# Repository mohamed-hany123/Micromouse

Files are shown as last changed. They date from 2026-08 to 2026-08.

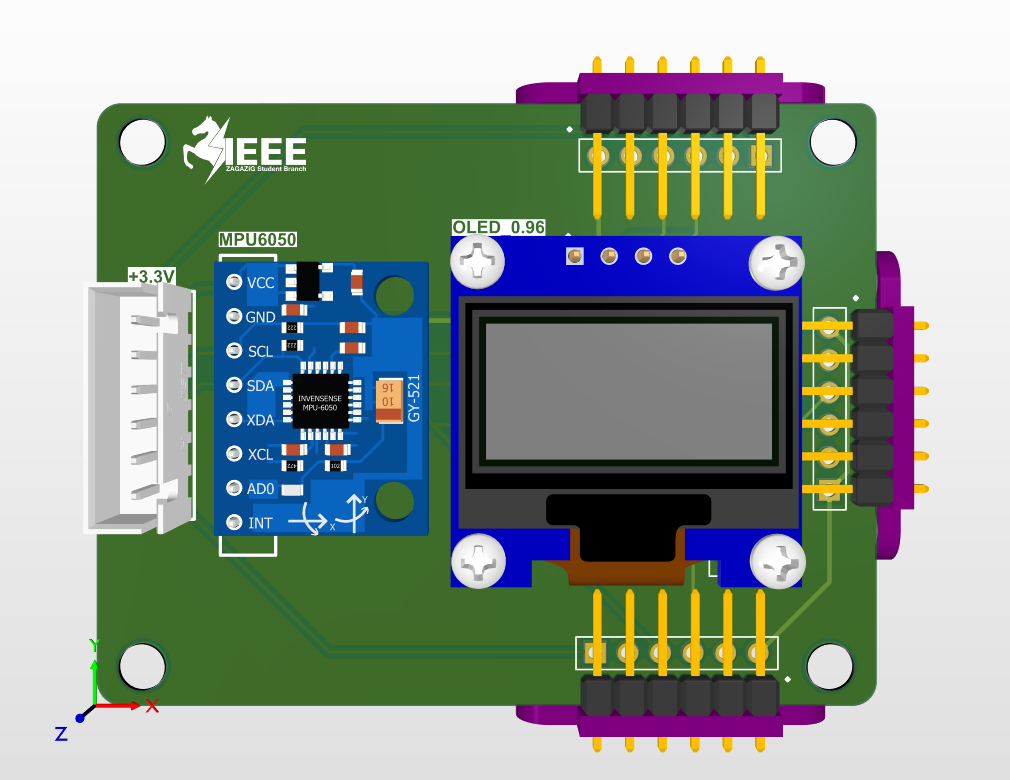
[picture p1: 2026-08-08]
media/Top_Floor_3d.png

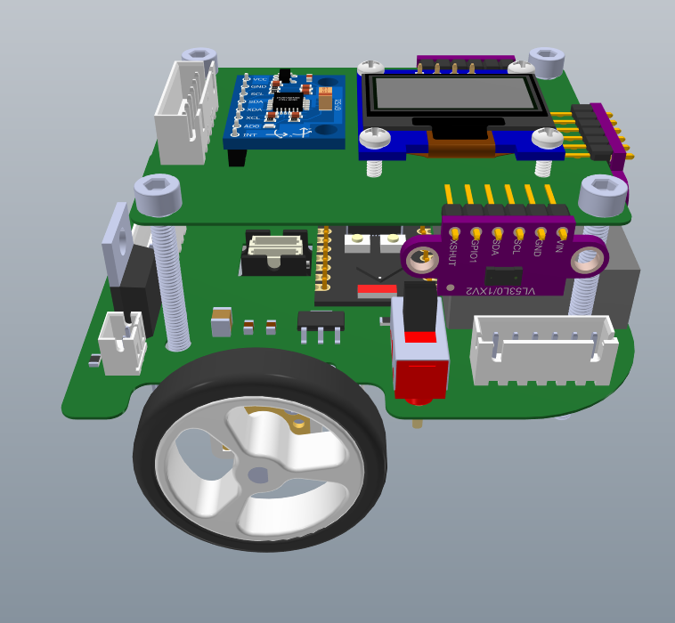
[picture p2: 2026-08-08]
media/3D_View.png

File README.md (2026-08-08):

# Micromouse
Micromouse robot designed for the IEEE Zagazig competition
# 🐭 Micromouse Robot

A custom-designed autonomous **Micromouse robot** developed for the **IEEE Zagazig competition**, where our team achieved **2nd place**.

The robot is designed to autonomously navigate a maze using distance sensors, determine its position and orientation, and control two DC motors for accurate movement.

> 🥈 **Competition Result: 2nd Place — IEEE Zagazig**

---

## 🏆 Competition

This project was developed and tested for an **IEEE Zagazig Micromouse competition**.

Our team achieved:

**🥈 2nd Place**

The competition required the robot to autonomously navigate a maze while accurately controlling its movement and responding to the maze structure.

---

## 🚀 Project Overview

The Micromouse is a small autonomous robot capable of navigating a maze without external control.

The robot uses multiple distance sensors to detect walls and obstacles, an IMU to measure orientation, wheel encoders for movement feedback, and a microcontroller to process sensor data and control the motors.

The project includes both the **electronic hardware** and **custom PCB design** developed specifically for the robot.

### Main Features

* Autonomous maze navigation
* Three front/side-facing ToF distance sensors
* Wheel encoder feedback
* IMU-based orientation measurement
* Closed-loop motor control
* Custom PCB designed in Altium Designer
* Dual DC motor drive
* Compact two-layer PCB design
* Dedicated power distribution and decoupling
* I²C communication between the ESP32-C3 and sensors

---

# 🧠 System Architecture

The main system can be divided into four sections:

```text
                  ┌──────────────────┐
                  │    ESP32-C3      │
                  │   Main MCU       │
                  └────────┬─────────┘
                           │
          ┌────────────────┼────────────────┐
          │                │                │
          ▼                ▼                ▼
   ┌────────────┐   ┌────────────┐   ┌────────────┐
   │ VL53L0X ×3 │   │  MPU6050   │   │  Encoders  │
   │ ToF Sensors│   │    IMU     │   │            │
   └────────────┘   └────────────┘   └────────────┘
                           │
                           │
                           ▼
                    ┌────────────┐
                    │  Control   │
                    │ Algorithms │
                    └─────┬──────┘
                          │
                          ▼
                    ┌────────────┐
                    │  DRV8833   │
                    │ Motor Driver│
                    └─────┬──────┘
                          │
                    ┌─────┴─────┐
                    ▼           ▼
                 Motor L     Motor R
```

---

# 🔌 Hardware

## Main Controller

### ESP32-C3

The **ESP32-C3** acts as the main controller of the robot.

It is responsible for:

* Reading the distance sensors
* Reading IMU data
* Processing encoder feedback
* Running the navigation and control algorithms
* Generating motor control signals
* Communicating with the peripheral devices through I²C and GPIO

---

## 📡 Distance Sensors

The robot uses **three VL53L0X Time-of-Flight sensors** for wall detection.

The sensors provide distance measurements that are used to determine the robot's position relative to the maze walls.

Using three sensors allows the robot to obtain information from multiple directions while navigating.

### I²C Addressing

Because the VL53L0X sensors share the same default I²C address, the design uses the sensors' shutdown/control pins to initialize them individually and assign unique I²C addresses.

This allows all three sensors to operate on the same I²C bus.

---

## 🧭 MPU6050

An **MPU6050 IMU** is used to obtain orientation and motion information.

The IMU provides:

* 3-axis accelerometer
* 3-axis gyroscope

The gyroscope data can be used to estimate the robot's rotation during turns and improve movement accuracy.

---

## ⚙️ Motor Driver

The robot uses a **DRV8833 dual H-bridge motor driver** to control the two DC motors.

The driver provides independent control of:

* Left motor
* Right motor

The ESP32-C3 generates the required control signals to control motor direction and speed.

---

## 🔄 Encoders

The motors include wheel encoders that provide feedback about wheel rotation.

Encoder feedback allows the controller to estimate:

* Distance traveled
* Wheel speed
* Difference between left and right wheel movement
* Movement accuracy during straight-line motion
* Rotation during turns

This feedback is important for implementing closed-loop motion control.

---

# 🖥️ PCB Design

The PCB was designed using **Altium Designer**.

The custom board integrates the major electronics required by the Micromouse into a single compact PCB.

### PCB Design Considerations

Several design considerations were taken into account during PCB development:

* Power distribution
* Decoupling capacitors
* Motor-driver current paths
* Sensor communication
* I²C routing
* Grounding
* Separation of noisy motor circuitry from sensitive sensors
* Compact component placement
* Connector accessibility
* Manufacturability

The PCB contains dedicated circuitry for the MCU, sensors, motor driver, power system, and external connections.

---

# ⚡ Power System

The PCB includes the required power distribution for the robot's electronics and motors.

Separate consideration was given to the motor supply and the low-voltage digital electronics to reduce the effect of motor switching noise on the sensors and microcontroller.

Decoupling capacitors were placed close to the relevant IC power pins to improve supply stability and reduce high-frequency noise.

---

# 📐 Hardware Files

The repository contains the hardware design files used during development.

The hardware files include the PCB design, schematic, component libraries, manufacturing files, and other supporting design files.

---

# 🧪 Testing & Verification

The hardware was tested throughout the development process before being used in the competition.

Testing included:

* Power supply verification
* Motor driver testing
* Sensor communication testing
* I²C communication
* Encoder feedback
* IMU measurements
* Motor direction and speed control
* PCB electrical-rule checking
* PCB design-rule checking
* Full robot movement testing
* Maze navigation testing

---

# 🛠️ Tools & Technologies

| Category | Technology |
| --- | --- |
| Microcontroller  | ESP32-C3 |
| Distance Sensors | VL53L0X ×3 |
| IMU | MPU6050 |
| Motor Driver | DRV8833 |
| Motors | DC Gear Motors with Encoders |
| PCB Design | Altium Designer |
| Communication | I²C |
| Motor Control | PWM |
| Programming | C / Embedded C |
| Manufacturing | Custom PCB |

---

# 📁 Repository Structure

```
Micromouse/
│
├── Hardware/
│    ├── Bottom_Floor/
│    ├── Full_project/
│    ├── Top_floor/
│   
│  
│
│
├── docs/
│      Micromouse_BOM.pdf
│      Micromouse_Calculations_IEEE_RAS.pdf
│
├── Media/
│   ├── Images
│
│
└── README.md
```

---

# 👥 Team

This was a team project developed for the IEEE Zagazig competition.

**Team Members:**

* Mohamed Hany 
* Abdallah Ahmed

### My Contribution

My main contributions to the project included:

* PCB design and development
* Schematic design
* Component selection
* ESP32-C3 hardware integration
* Sensor integration
* Motor-driver integration
* Power distribution
* PCB routing and layout
* Hardware testing and debugging

# 🏁 Result

## 🥈 2nd Place — IEEE Zagazig

The completed Micromouse successfully competed in the IEEE Zagazig competition and achieved **2nd place**.

The project provided practical experience in:

* Embedded systems
* PCB design
* Sensor integration
* Motor control
* Power electronics
* Hardware debugging
* Autonomous robotics
* Team-based engineering

---

# 📜 License

This project is provided for educational and portfolio purposes.

Please contact the project contributors before using the hardware design commercially.

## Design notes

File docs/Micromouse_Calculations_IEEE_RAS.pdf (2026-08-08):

# Micromouse

## Final Project — Calculations & Justification

IEEE ZSB · RAS Chapter — PCB Design Track Final Project

## 1 PCB Copper Trace Width Calculations

## 2 Power Calculations of All Components

## 3 Microcontroller Selection Justification

## 4 Battery Lifetime Calculations

## 1 PCB Copper Trace Width Calculations

Calculated using the IPC-2221 standard for external (top/bottom layer) traces, 1oz/ft² copper, 10°C allowable temperature rise.

## Area (mils²) = (I / (k × ∆T

0.44))⁽¹/0.725)

## | Width (mils) = Area / 1.37

I = current (A), ∆T = 10°C, k = 0.048.

## 1.1 — Top Floor (Sensors)

Net | Worst-Case I | Calc. Min. | Implemented | Margin
3.3V / GND (power) | 0.139 A | 0.020 mm | 0.3533 mm | 17.7×
Signal traces (SDA, SCL, XSHUT) | < 10 mA | < 0.01 mm | 0.25 mm | Ample

## 1.2 — Bottom Floor (Power, MCU, Motor Driver)

Net | Worst-Case I | Calc. Min. | Implemented | Margin
Main power rail (Fuse → Switch → Protection → VCC) | 0.789 A | 0.218 mm | 0.4 mm | 1.83×
DRV8833 VM | 0.600 A | 0.149 mm | 0.4 mm | 2.68×
Motor outputs → Motor Left / Right (each) | 0.300 A | 0.057 mm | 0.25 mm | 4.39×
Regulator path (7.4V_Safe → AMS1117 → 5V → ESP32) | 0.189 A | 0.030 mm | 0.4 mm | 13.3×
Signal traces (motor control, encoders, ADC divider) | < 10 mA | < 0.01 mm | 0.254 mm | Ample

## 2 Power Calculations of All Components

Calculated using P = V × I at each component's actual operating voltage.

Component | V | I (typ.) | P | Source
ESP32-C3 (active, radios off) | 3.3V | 45 mA | 0.149W | Espressif datasheet
3× VL53L0X ToF (30mA ea.) | 3.3V | 90 mA | 0.297W | ST datasheet
MPU6050 IMU | 3.3V | 3.6 mA | 0.012W | InvenSense datasheet
OLED 0.96in (SSD1306) | 3.3V | 20 mA | 0.066W | Manufacturer datasheet
2× Encoders (10mA ea., estimated) | 3.3V | 20 mA | 0.066W | Estimated
DRV8833 quiescent | 3.3V | 5 mA | 0.017W | Typical
AMS1117-5.0 quiescent | 7.4V | 5 mA | 0.037W | Typical
Battery divider bleed (100k+33k) | 7.4V | 0.056 mA | 0.0004W | Calculated
Q1 (IRF9540) loss — idle | — | @ 0.189A | 0.007W | Rds(on)=0.20Ω
Q1 (IRF9540) loss — typical | — | @ 0.439A | 0.039W | Rds(on)=0.20Ω
Q1 (IRF9540) loss — worst-case | — | @ 0.789A | 0.125W | Rds(on)=0.20Ω
2× N20 motors — typical (estimated) | 7.4V | 250 mA | 1.850W | ~40% of stall
2× N20 motors — worst-case stall | 7.4V | 600 mA | 4.440W | Manufacturer datasheet

## System Totals

Every regulation stage (AMS1117, Super Mini onboard regulator) is linear, not switching — current is approximately conserved through each stage rather than reduced, so every downstream component's current is reflected directly in what the battery must supply.

Scenario | Total Current | Total Power | Q1 Loss Share
Logic + sensors only (motors idle) | 189 mA | 1.399 W | 0.5%
Typical driving (motors normal) | 439 mA | 3.249 W | 1.2%
Worst-case (both motors stalled) | 789 mA | 5.839 W | 2.1%

## 3 Microcontroller Selection Justification

## Chosen microcontroller: ESP32-C3 Super Mini

Required: 4 motor-driver control pins, 4 quadrature encoder channels, a 2-pin I2C bus shared by 5 devices, 2 GPIO-controlled ToF address lines, and 1 ADC pin for battery sensing — 13 GPIOs total.

## 3.1 — ESP32-C3 Super Mini vs. a Standard 30/38-pin ESP32 DevKit

Spec | ESP32-C3 Super Mini | Standard 30/38-pin DevKit
Board footprint | 22.5 × 18 mm = 405 mm² | ~55 × 28 mm = 1,540 mm² (~3.8× larger)
CPU | Single-core RISC-V | Dual-core Xtensa LX6 (higher idle draw)
Onboard extras | Small onboard 3.3V LDO only | USB-UART bridge chip + large USB connector + full regulator
Usable GPIOs | 13 (exact match) | 30-38 (17-25 unused in this design)
Mounting | Pluggable, small 2.54mm header | Larger socket footprint or permanent solder-down
- 405mm² footprint is ~3.8× smaller than a standard DevKit's ~1,540mm² — a direct, quantifiable contribution to the 11×11cm limit and smallest-robot bonus
- A DevKit's onboard USB-UART bridge and full-size USB connector exist only for plug-and-program convenience — functionality this design moves off-board by programming the Super Mini externally before mounting, making that circuitry pure dead weight here
- 13 GPIOs is an exact match to this design's requirement; a 30/38-pin DevKit would leave 17-25 pins permanently unused
- Both chip families include WiFi/BLE by default; since this design uses neither, the smaller/cheaper C3 package is strictly better with no functional trade-off

## 3.2 — Handling the Tight Pin Budget Safely

- GPIO9 (BOOT button pin) carries only a motor-driver output signal, never an encoder input — a driver output is always actively set by firmware and cannot glitch the boot sequence the way an unpredictable encoder state could
- GPIO8 (onboard status LED) is assigned to a non-critical encoder channel — the LED flickering with wheel rotation is cosmetic only

## 4 Battery Lifetime Calculations

## Final Battery Specification

Spec | Value
Type / configuration | 2× 3.7V LiPo cells (ECOCELL) in series = 7.4V nominal
Capacity | 1000 mAh
Dimensions (per cell) | 35 × 25 × 10 mm
Weight (per cell / pair) | 22g / 44g total
Max charge current | 500 mA (0.5C) — per cell, charged individually
Max discharge current | 1000 mA (1C) max; 500 mA (0.5C) recommended continuous
Protection | Built-in per-cell: overcharge, over-discharge, short-circuit

## Step 1 — Runtime at Typical Operating Current

## Runtime (h) = Capacity (Ah) / Current (A)

Runtime = 1.0 Ah / 0.439 A ≈ 2.28 hours (~137 minutes).

## Step 2 — Runtime at Worst-Case Current

Runtime = 1.0 Ah / 0.789 A ≈ 1.27 hours (~76 minutes) — both motors permanently stalled; pessimistic-case only.

## Step 3 — Discharge Rate Check

This battery specifies fixed discharge limits: 500mA recommended continuous, 1000mA absolute maximum. Typical current (439mA) stays under the recommended limit; worst-case current (789mA) exceeds it by 58% but remains under the 1000mA absolute maximum — acceptable for this short-duration competition project.

## Step 4 — Practical Safety Margin for Competition Use

## Required capacity = Current × Runtime needed × 1.25

For a 15-minute session: 0.439A × 0.25h = 0.110 Ah, ×1.25 ≈ 137 mAh minimum. The chosen 1000mAh pack provides over 7× this minimum.

## Step 5 — Charging Procedure

Two independently-protected single cells, not one factory 2S pack — charge each cell individually: disconnect the series link, charge each 3.7V cell separately through its own JST-PH connector at or under 500mA, then reconnect in series for use.

Prepared for IEEE ZSB · RAS chapter - PCB Design track | Final Project: Micromouse

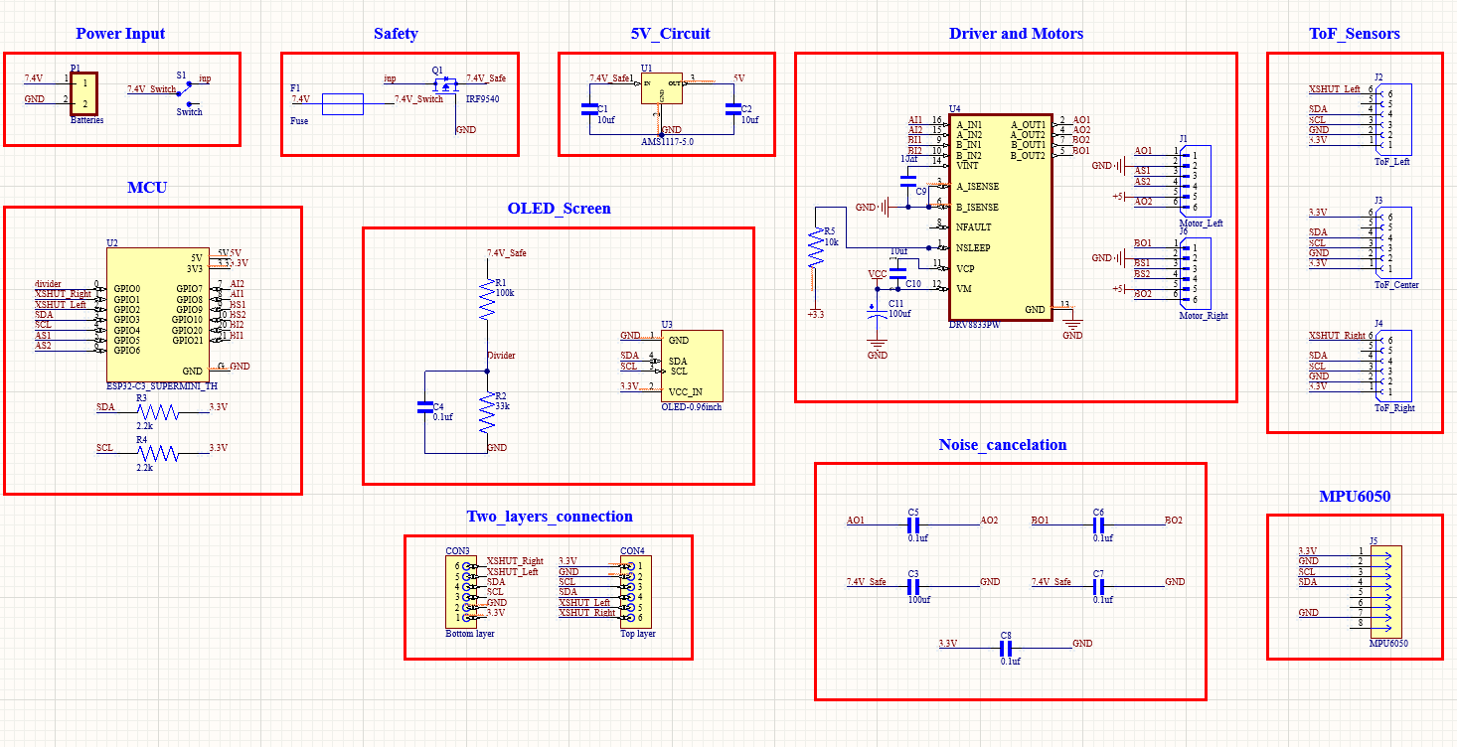
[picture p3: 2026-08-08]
media/Full_Schematic.png

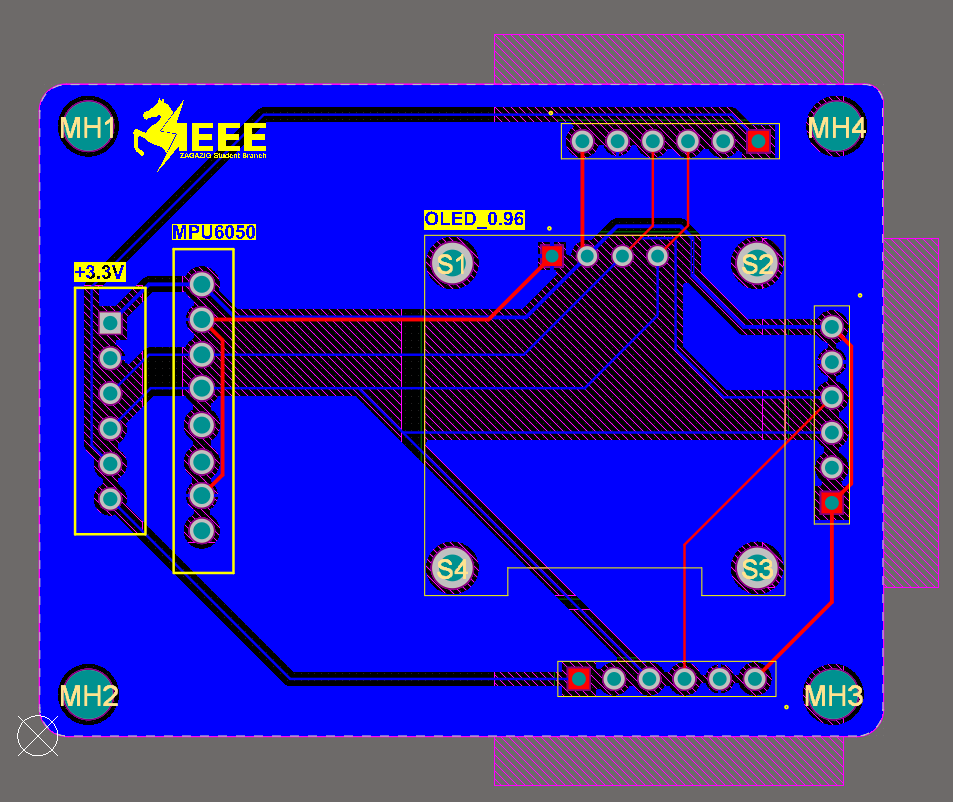
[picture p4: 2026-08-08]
media/Top_Floor_2d.png

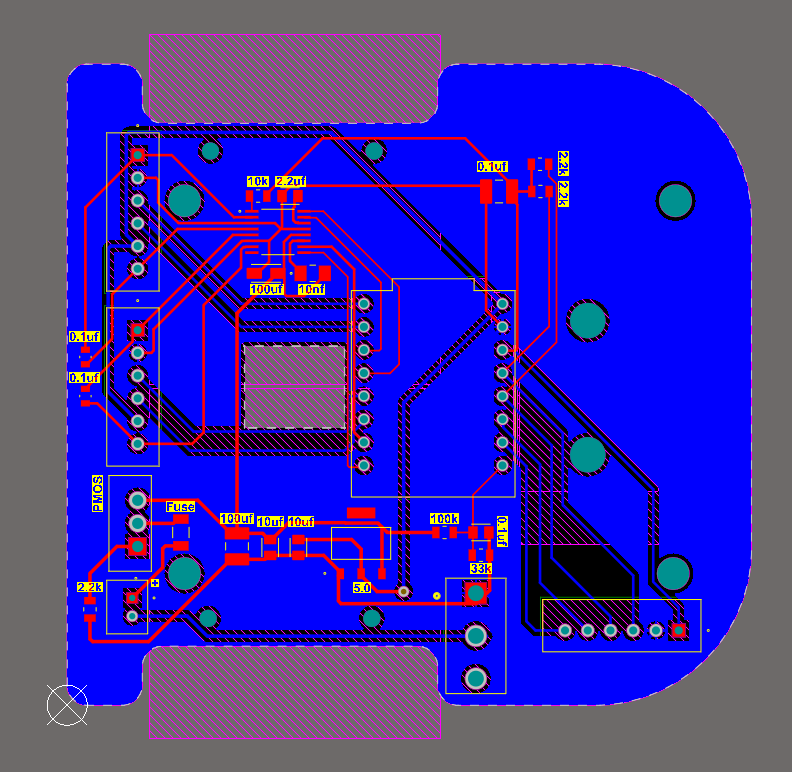
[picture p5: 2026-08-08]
media/Bottom_Floor_2d.png

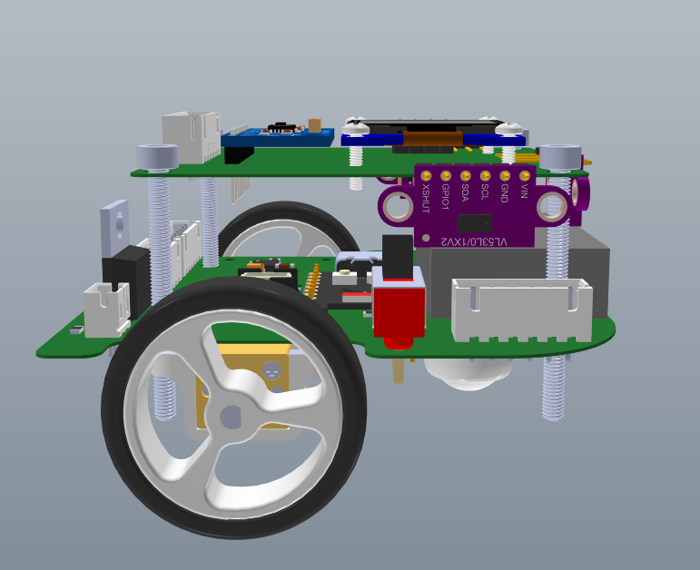
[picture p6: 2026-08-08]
media/Side_View.png

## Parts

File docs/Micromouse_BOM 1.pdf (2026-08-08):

Component | Store Link
VL53L0X ToF Distance Sensor (×3) | https://microohm-eg.com/gy-53-vl53l0x-laser-tof-flight-time-ranging-sensor-module-high-precision-time-of-flight-distance-measurement-with-pwm-serial-output/
MPU6050 IMU — GY-521 Breakout (×1) | https://makerselectronics.com/product/mpu-6050-imu-sensor-module-with-6-dof-gyroscope-accelerometer/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
OLED Display 0.96" SSD1306 (×1) | https://makerselectronics.com/product/oled-display-i2c-4-pin-0-96%E2%80%B3-2/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
Resistor 2.2kΩ, SMD 0805 (×2) | https://makerselectronics.com/product/chip-resistor-smd-2-2k%cf%89-%c2%b11-0-125w-%c2%b1100ppm-%e2%84%83-0805/
Resistor 100kΩ, SMD 0805 (×1) | https://makerselectronics.com/product/chip-resistor-smd-100k%cf%89-%c2%b11-0-125w-%c2%b1100ppm-%e2%84%83-0805/
Resistor 33kΩ, SMD 0805 (×1) | https://makerselectronics.com/product/chip-resistor-smd-33k%cf%89-%c2%b11-0-125w-%c2%b1100ppm-%e2%84%83-0805/
Resistor 10kΩ, SMD 0805 (×1) | https://makerselectronics.com/product/chip-resistor-smd-10k%CF%89-%C2%B15-0-125w-%C2%B1100ppm-%E2%84%83-0805/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
6-pin JST Connector, JST-PH 2.0mm (×4) | https://makerselectronics.com/product/b6b-xh-a-jst-xh-6-pin-header-2-5mm/
M3 Standoff / Spacer (×4) | https://www.ram-e-shop.com/ar/shop/spacer-cupper-15mf-copper-pcb-spacer-15mm-m-f-6291?category=121
M3 Screw + Nut (×4) | https://www.ram-e-shop.com/ar/shop/spacer-cupper-15mf-copper-pcb-spacer-15mm-m-f-6291?category=121
2-pin JST Connector, JST-PH 2.0mm (×1) | https://makerselectronics.com/product/b2b-xh-a-jst-xh-2-pin-header-2-5mm/
Fuse — PTC Resettable, SMD 1206 (×1) | https://makerselectronics.com/product/resettable-fuses-ptc-6v-1-1a-wt-1206-110-smd/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
Switch — SPDT Slide Switch (×1) | https://makerselectronics.com/product/slide-switch-3-pin-on-off-spdt/
MOSFET — IRF9540, P-channel, TO-220 (×1) | https://makerselectronics.com/product/irf9540-p-channel-power-mosfet-transistor-to-220-100v-19a-0-20%CF%89/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
Voltage Regulator — AMS1117-5.0, SOT-223 (×1) | https://makerselectronics.com/product/goodwork-ams1117-5-70db120hz-1a-fixed-5v-positive-18v-sot-223-dropout-regulators-smd/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
Capacitor 10µF, SMD 0805 (×4) | https://uge-one.com/product/smd-chip-ceramic-capacitor-size-0805-10uf/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
Capacitor 0.1µF, SMD 0805 (×6) | https://uge-one.com/product/smd-chip-ceramic-capacitor-size-0805-100nf/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
Capacitor 2.2µF (6.3V), SMD (×2) | https://makerselectronics.com/product/multilayer-ceramic-capacitors-mlcc-smd-smt-2-2uf-%c2%b110-50v-0805/
Capacitor 0.01µF / 10nF (16V), SMD (×2) | https://uge-one.com/product/smd-chip-ceramic-capacitor-size-0805-10nf/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
ESP32-C3 Super Mini (×1) | https://makerselectronics.com/product/esp32-c3-super-mini-development/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
Motor Driver IC — DRV8833PWP, HTSSOP-16 (×1) | https://makerselectronics.com/product/drv8833-2-channel-dc-motor-driver/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
N20 Micro Gear Motor w/ Encoder — JGA12-N20 (×2) | https://makerselectronics.com/product/jga12-n20-micro-metal-gear-dc-motor/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
LiPo Battery Cell — ECOCELL 3.7V 1000mAh (×2) | https://store.fut-electronics.com/products/3-7v-rechargeable-polymer-lithium-ion-battery-ecocell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
Metal Caster Wheel (x1) | https://uge-one.com/product/caster-wheel-small/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
M2 Screw (×8) | https://microohm-eg.com/screw-m2-2mm-x-12mm-with-nut/
M2 Nuts (x8) | https://microohm-eg.com/screw-nut-m2-2mm-1pcs/
N20 Motor Mount Bracket | https://makerselectronics.com/product/n20-motor-mount-bracket/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
N20 Rubber wheel | https://microohm-eg.com/n20-44mm-miniq-rubber-wheel-for-n20-gear-motor/
Capacitor 100µF (6.3V), SMD (×1) | https://makerselectronics.com/product/multilayer-ceramic-capacitors-mlcc-smd-smt-6-3v-100uf-x5r-%C2%B120-1206/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

### Micromouse Final Project — Bill of Materials

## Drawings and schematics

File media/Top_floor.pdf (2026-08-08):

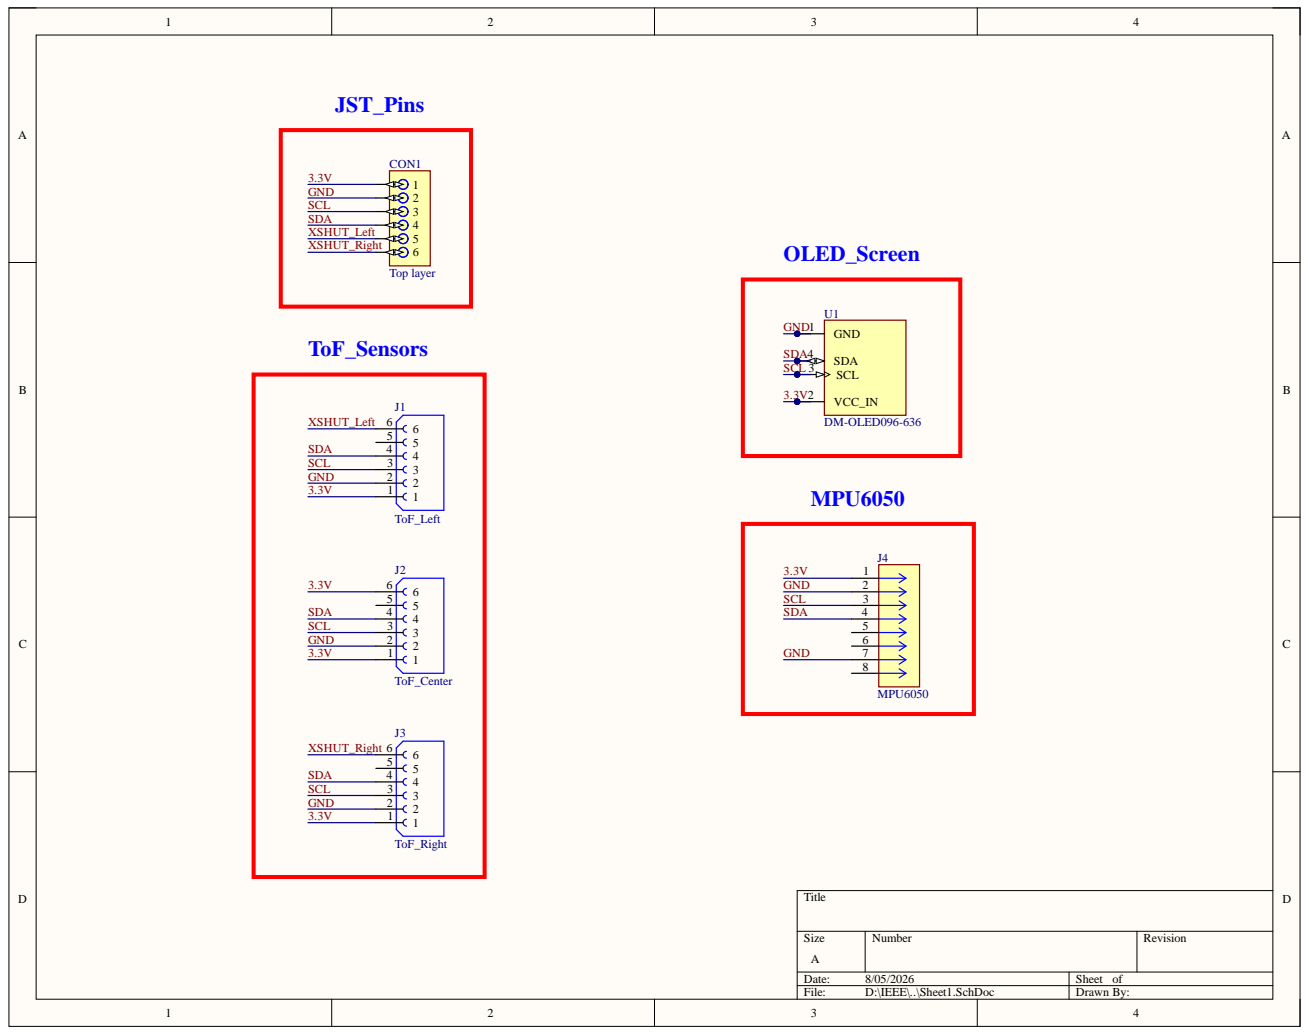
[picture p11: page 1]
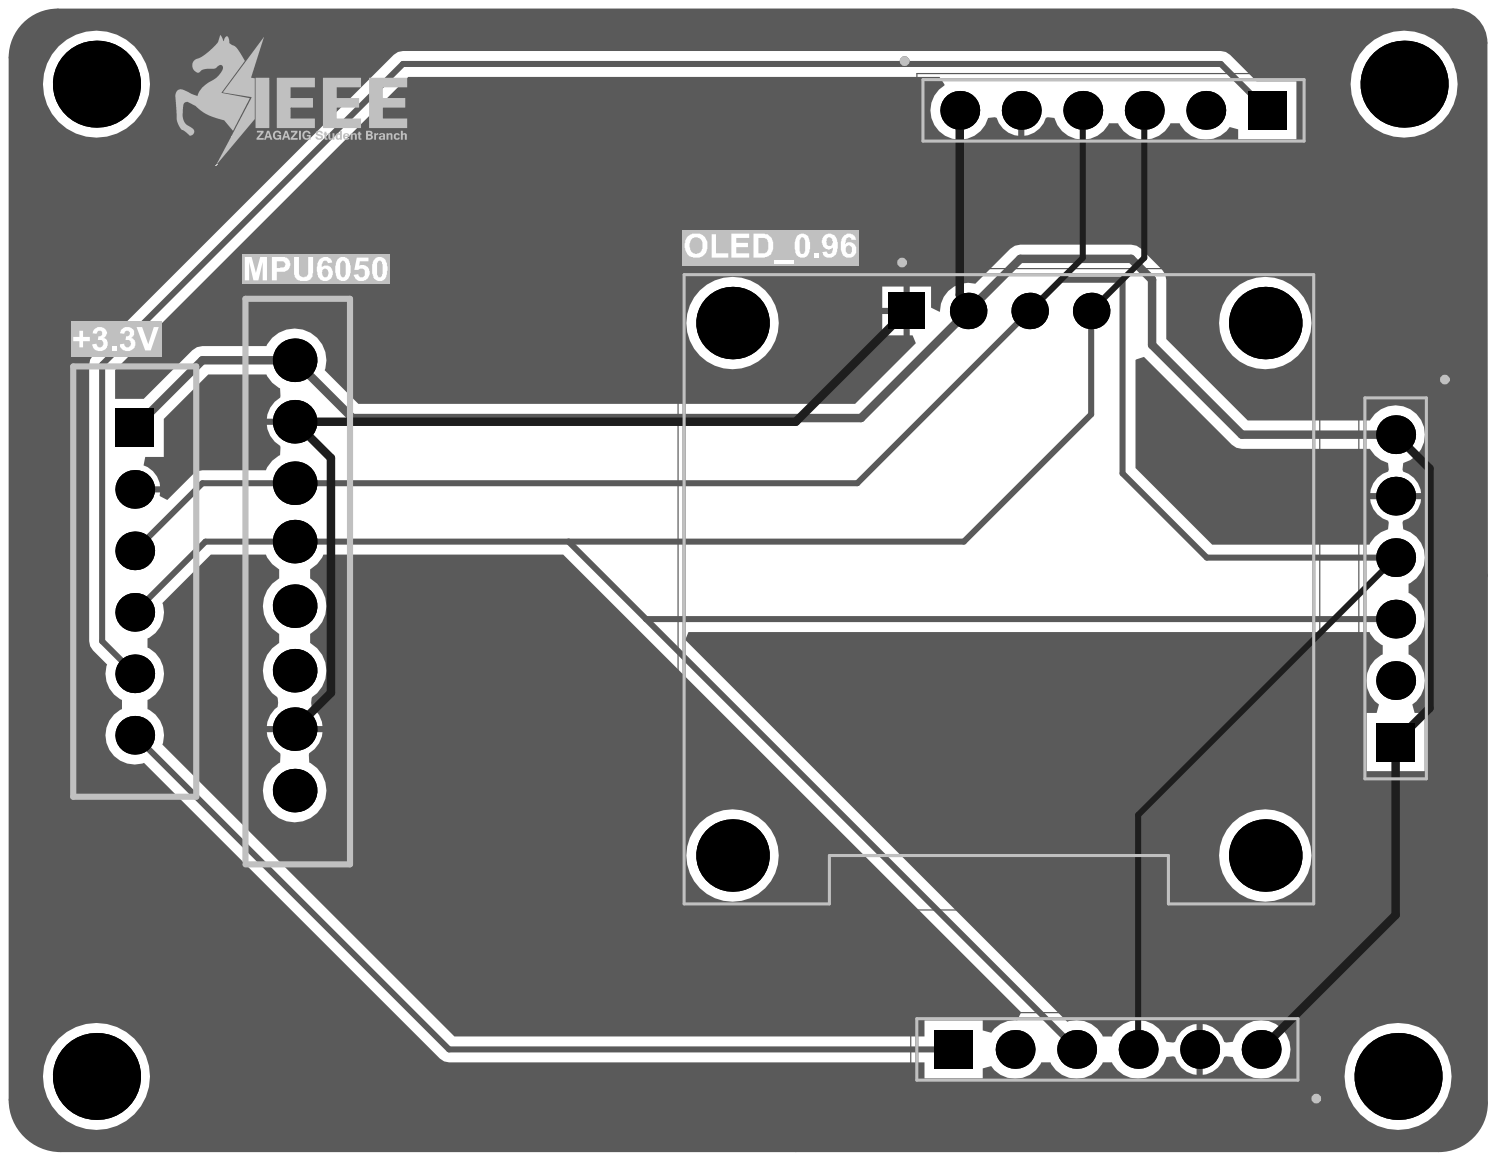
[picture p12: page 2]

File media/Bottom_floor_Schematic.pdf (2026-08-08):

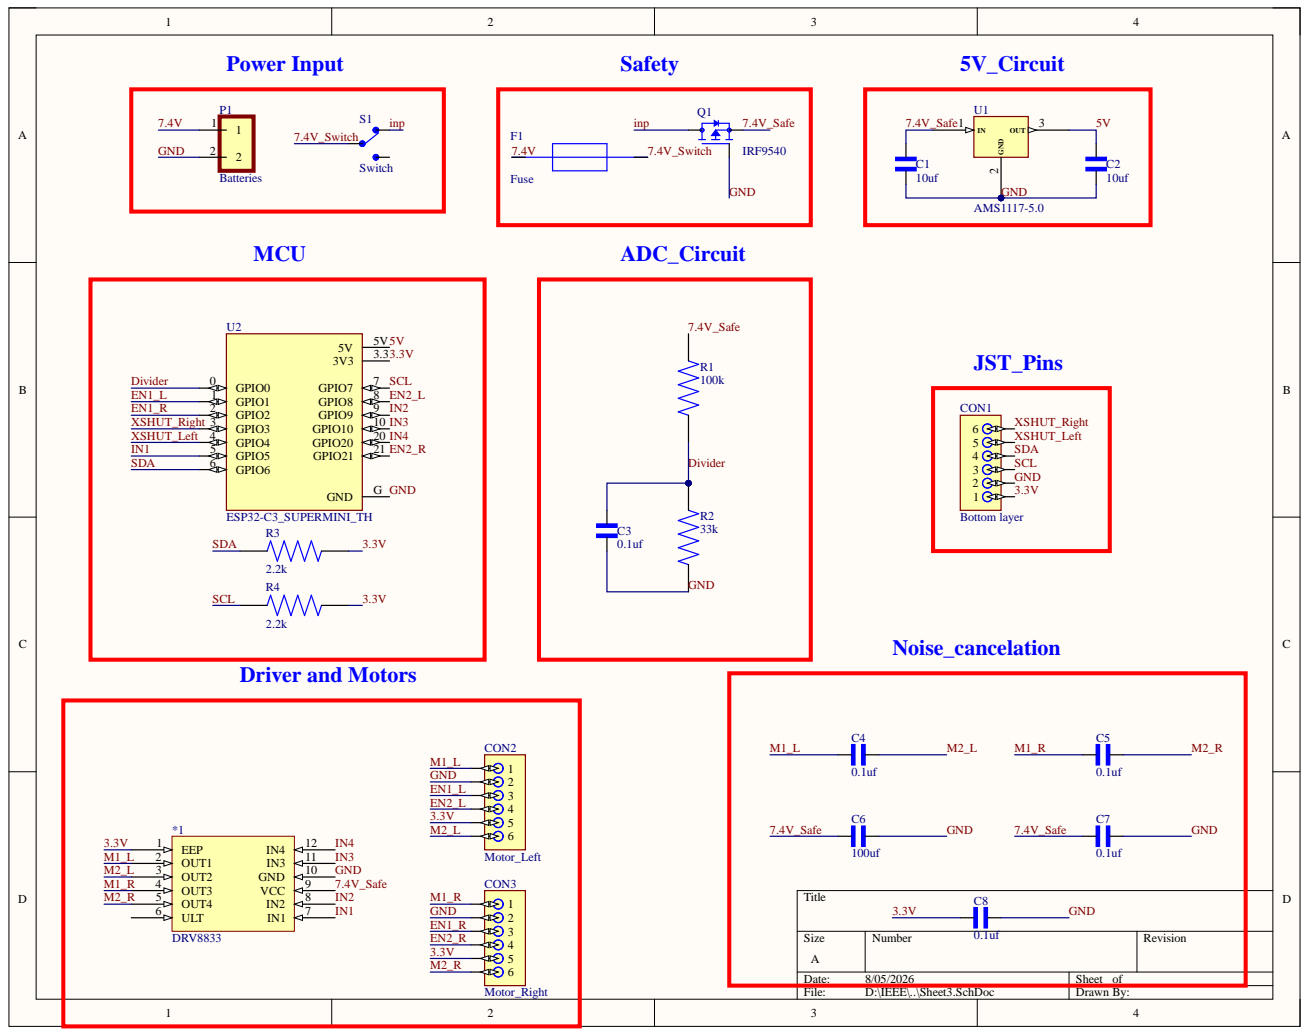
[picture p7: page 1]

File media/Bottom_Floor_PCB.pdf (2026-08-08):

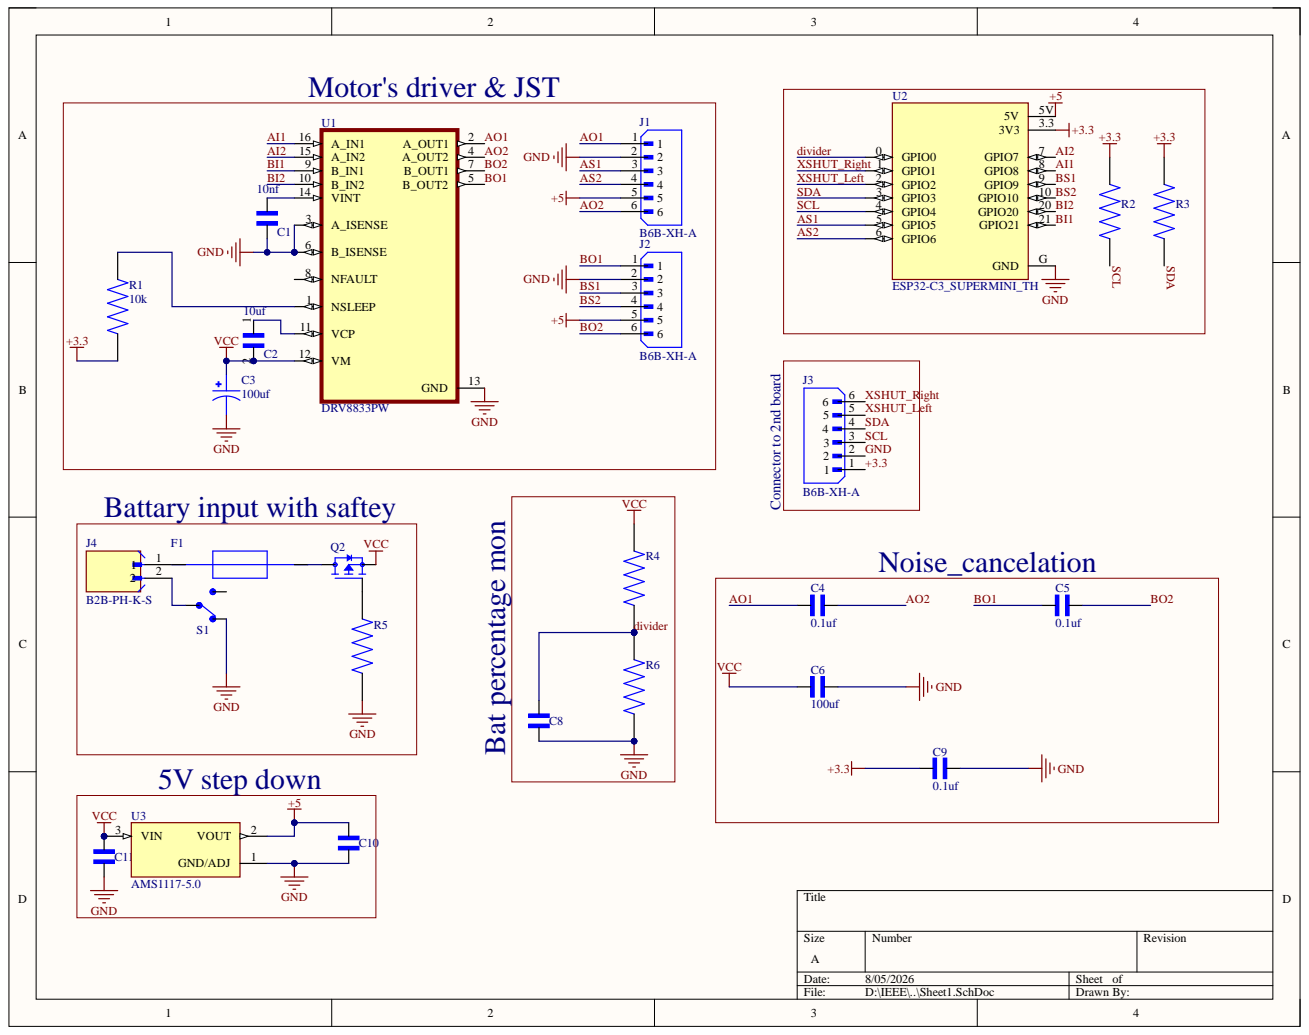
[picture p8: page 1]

Battary input with saftey

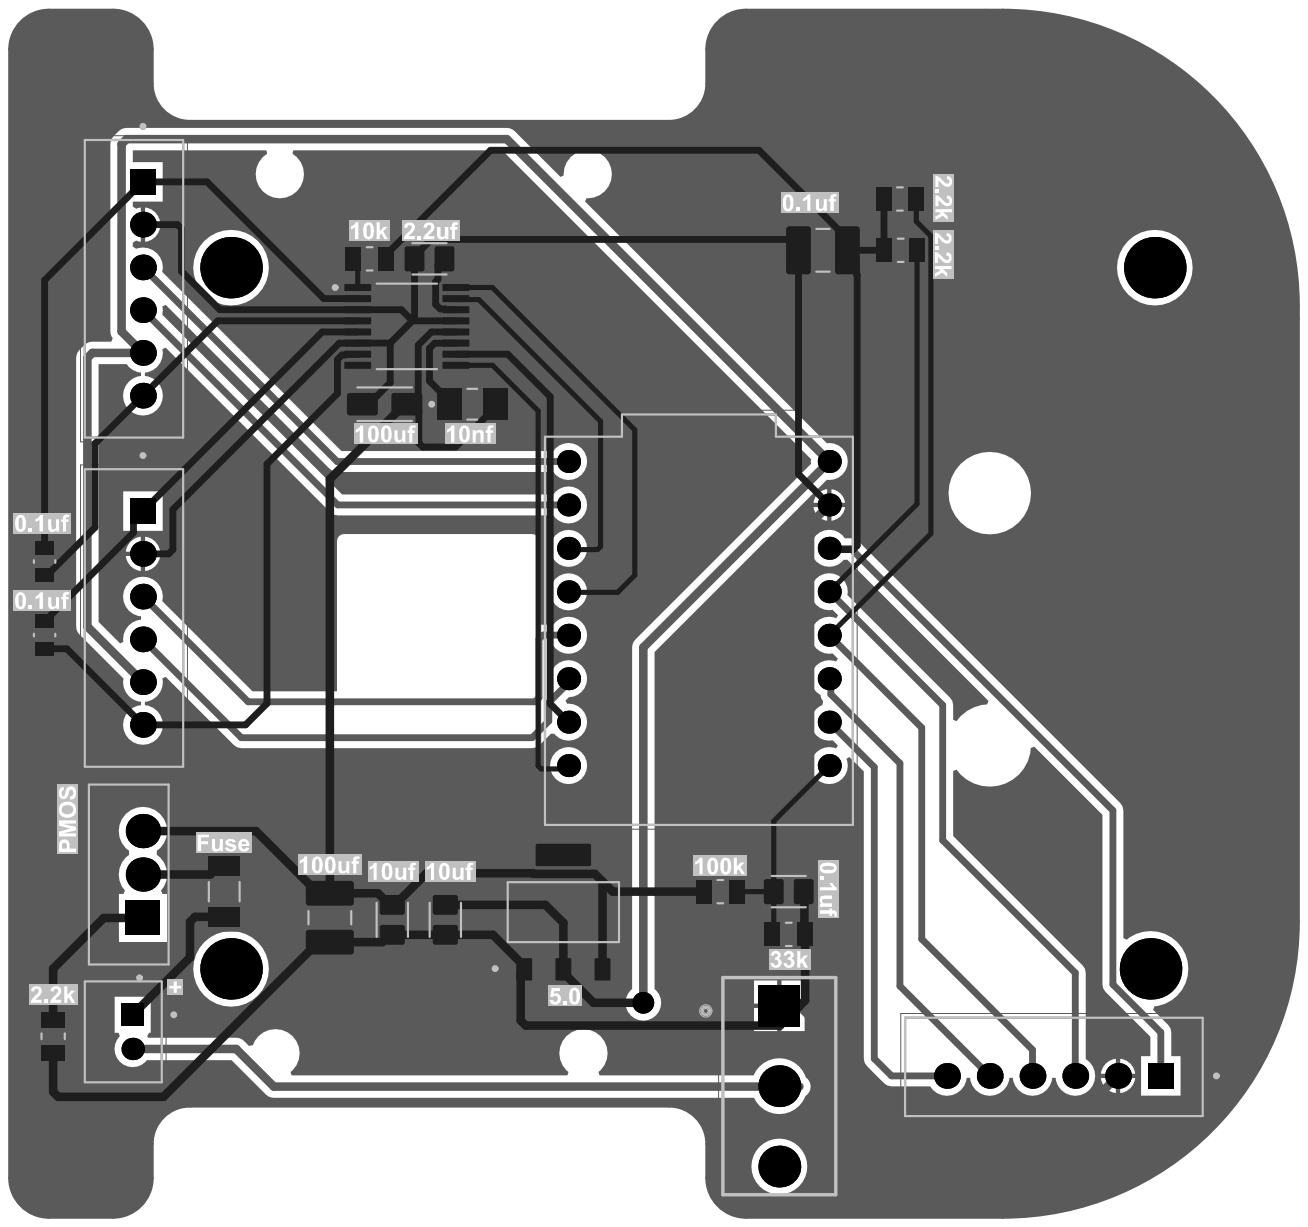
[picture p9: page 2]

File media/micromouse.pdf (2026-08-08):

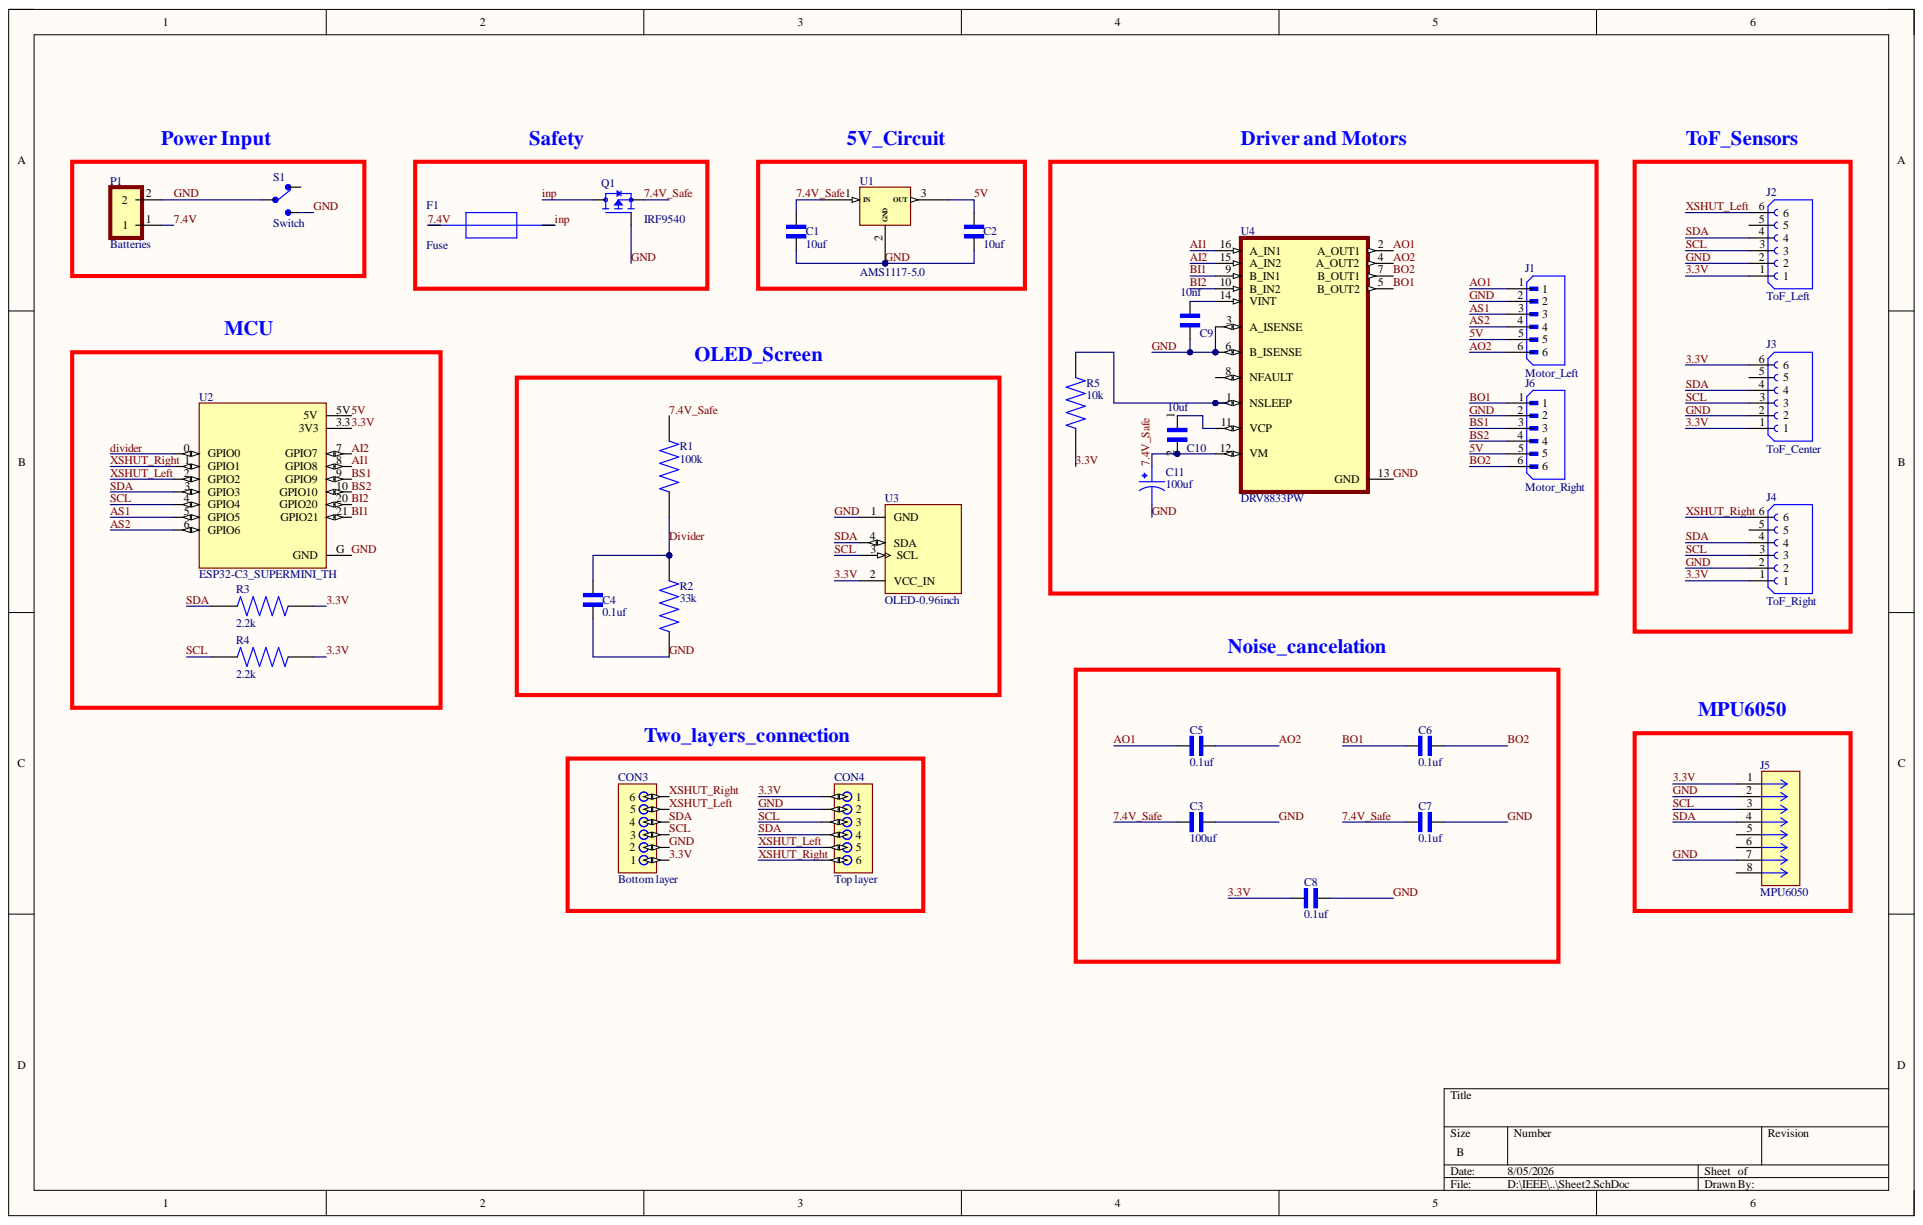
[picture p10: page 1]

Si z e | Num b er | Revi s i on

e : 8/05/ 20 2 6 | Sheet of
Fi l e : D : \IE E E \..\Sheet2.SchD o c | D rawn By:
